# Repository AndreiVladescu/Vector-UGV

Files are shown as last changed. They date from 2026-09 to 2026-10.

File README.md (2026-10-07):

V.E.C.T.O.R.

# V.E.C.T.O.R.

An 18-DOF hexapod research platform: a smart controller per leg on CAN, a Raspberry Pi CM5 carrier, camera and SDR payload, ELRS / Wi-Fi / 4G links. Built for the [PCBWay 9th Project Design Contest](https://www.pcbway.com/activity/9th-project-design-contest.html).

- `docs/`: spec, connector pinouts, power budget, servo names and calibration
- `hardware/`: one KiCad project per board, shared library in `lib/`
- `mechanical/`: Fusion 360 exports (STEP, STL), harness drawings
- `firmware/`: STM32C092 code for the leg and power nodes, CAN bootloader
- `software/`: CM5 / Pi 5 side: ROS 2 workspace, tools, Docker
- `protocol/vector.dbc`: CAN message definitions, used by firmware and host
- `test-tools/`: bench sketches, e.g. `servo_test` (Arduino Uno, set a servo angle over serial and read the pot)

Start with `docs/spec.md`.

## Try it without hardware

Everything below runs on a PC with Ubuntu 24.04 or Linux Mint 22 and ROS 2 Jazzy (install commands in [`software/README.md`](software/README.md#desktop-setup-mint-223--ubuntu-2404)). The leg nodes run their real firmware logic against simulated servos on a virtual CAN bus.

```sh
cd software/ros2_ws
source /opt/ros/jazzy/setup.zsh                 # or setup.bash
colcon build --symlink-install && source install/setup.zsh

# virtual CAN bus (again after every reboot)
sudo modprobe vcan
sudo ip link add dev vcan0 type vcan && sudo ip link set up vcan0

ros2 run vector_hw sim_legs vcan0 --calibrated --limits -45.8,45.8,-80.2,80.2,-149,17  # terminal 1: six legs
ros2 launch vector_bringup robot.launch.py hardware:=can can_interface:=vcan0   # terminal 2: robot + rviz
ros2 run teleop_twist_keyboard teleop_twist_keyboard                           # terminal 3: drive (i, j, l, J, L, t, b, k)
candump vcan0 | cantools decode ../../protocol/vector.dbc                      # optional: watch the bus
```

Each new terminal needs the two `source` lines. Stop `sim_legs` while the robot runs and the hardware drops out after 100 ms, the same as it would with a dead leg. Without `--calibrated` the legs start like fresh boards; `leg_config.py` calibrates them (see `software/README.md`).

Without CAN: `robot.launch.py` alone (mock joints), or `sim_gazebo.launch.py world:=rough level:=true` for physics.

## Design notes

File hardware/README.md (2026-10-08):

# Hardware

One KiCad project per board: `side-board/`, `power-board/`, `carrier-cm5/`. The lib tables in each point to the shared library in `lib/`, so custom symbols and footprints go there.

- Connector pinouts come from `docs/interfaces.md`. Use the same footprint and pin order on both ends of a cable.
- Side board: draw the leg cell as one hierarchical sheet, use it three times, and copy the layout with KiCad's multichannel tools.
- Tag each fabbed revision (`side-board-revA`) and put the revision and git hash on the silkscreen. Gerbers, BOM and pick-and-place go in `<board>/production/<rev>/`.
- Hand assembly: 0402 minimum, one side where possible, test points and 0 Ω links on every rail.

`BOM_LCSC.csv` is a second way to buy the main parts for one robot: LCSC part numbers, quantities, prices and stock checked on 2026-10-08, and where each part is cheaper (LCSC, Mouser or TME). It loads straight into LCSC's BOM tool. Passives aren't in it yet.

## Power rails

Currents and loads are in `docs/power-budget.md`. No 5 V on the side boards: the CAN transceivers are 3.3 V parts (TI TCAN332DR).

```
PACK 4S3P 18650 (12.0–16.8 V)
│
└─ POWER BOARD ── BQ76952 high-side FETs ── VBAT
   │                                  (charging: BQ25798, fed by GX-12 12–24 V or USB-C PD 20 V)
   │
   ├─ LM5069 (hot-swap + e-stop) ── VBAT_L ──► SIDE BOARD L
   │                                  ├─ TPS56A37 ── 6V0_LEG1 ── 3× MG996R (+ pots)
   │                                  ├─ TPS56A37 ── 6V0_LEG2 ── 3× MG996R (+ pots)
   │                                  ├─ TPS56A37 ── 6V0_LEG3 ── 3× MG996R (+ pots)
   │                                  └─ low-Iq buck ── 3V3_LEG ── 3× STM32C092, 3× CAN xcvr,
   │                                                              3× VL53L1X, 3× INA181
   │
   ├─ LM5069 (hot-swap + e-stop) ── VBAT_R ──► SIDE BOARD R   (same as L)
   │
   ├─ 5 V / 6 A buck ── 5V_SYS ──► CARRIER
   │                                  ├─ CM5 ── 3V3 / 1V8 (CM5's own outputs)
   │                                  ├─ 2× USB-A (current-limit switches)
   │                                  ├─ SDR (AD9363), fan
   │                                  └─ 3V3_M2 ── Hailo M.2 (optional)
   │
   ├─ VBAT_SYS ──► CARRIER
   │                ├─ 3.8 V buck ── 3V8_LTE ── EC25-EUX
   │                └─ small 5 V buck ── gimbal (2× SG90)
   │
   └─ 3V3_PWR (TBD) ── STM32C092 on the power board, BQ76952 comms
```

3.3 V is made locally on each side board, not sent over the CAN harness: the STM32C0 ADC uses VDD as its reference, so a remote 3.3 V would put servo current noise on the pot and current readings, and a short on one side would take down the other.

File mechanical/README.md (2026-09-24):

# Mechanical

The live design lives in Fusion 360. This folder holds exports taken at milestones:
- `cad/fusion/`: `.f3z` archives
- `cad/step/`: assembly and parts
- `cad/pcb/`: board outlines (DXF, Fusion to KiCad) and board STEPs (KiCad to Fusion)
- `stl/`: named `<part>_<material>_x<qty>.stl`
- `harness/`: cable drawings

Board outline loop: sketch the outline and holes on the body in Fusion, export DXF, import to KiCad Edge.Cuts. After layout, export STEP back and check fit through the full leg range.

The free Fusion licence allows 10 editable documents, so keep most parts as internal components of one assembly. Keep leg lengths as user parameters, since the same numbers go in the URDF.

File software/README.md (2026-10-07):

# Software

Runs on the Pi 5 during development and on the CM5 later: Raspberry Pi OS, with ROS 2 Jazzy in Docker.

Packages in `ros2_ws/src/`:
- `vector_description`: URDF and `config/legs.yaml`, the one place leg lengths and hip positions live; `vector_cad.urdf.xacro` is the full Fusion 360 model, generated from the raw export `vector_cad_raw.urdf.xacro` by `tools/cad_urdf.py` (run it after every export; view the result with `ros2 launch vector_bringup view_cad.launch.py`)
- `vector_gait`: kinematics and gait in plain C++ (`vector_core`, no ROS), plus `gait_node`
- `vector_hw`: ros2_control hardware for the leg nodes over SocketCAN, plus `sim_legs` (the leg firmware logic with simulated servos) and `leg_config.py` (calibration and settings over CAN)
- `vector_bringup`: launch files, controller config, rviz config, Gazebo worlds
- `vector_link`: ExpressLRS (`elrs.py`), the cmd_vel mux and link watchdog, the operator page
- `vector_nav`: waypoint follower and obstacle grid
- `vector_tof`: the nose board's VL53L8CX
- `vector_io`: the carrier's IO MCU over UART2 (lidar, GNSS, ELRS frames, LoRa, housekeeping) and its flasher
- `vector_imu`: LSM6DSV16X on the carrier and MMC5983MA on the nose board -> `imu`, `mag`
- later: `vector_perception`

## Desktop setup (Mint 22.3 / Ubuntu 24.04)

```sh
sudo apt install curl
export ROS_APT_SOURCE_VERSION=$(curl -s https://api.github.com/repos/ros-infrastructure/ros-apt-source/releases/latest | grep -F tag_name | awk -F'"' '{print $4}')
curl -L -o /tmp/ros2-apt-source.deb "https://github.com/ros-infrastructure/ros-apt-source/releases/download/${ROS_APT_SOURCE_VERSION}/ros2-apt-source_${ROS_APT_SOURCE_VERSION}.$(. /etc/os-release && echo $UBUNTU_CODENAME)_all.deb"
sudo dpkg -i /tmp/ros2-apt-source.deb
sudo apt update
sudo apt install ros-jazzy-desktop ros-jazzy-ros2-control ros-jazzy-ros2-controllers \
  ros-jazzy-xacro ros-jazzy-teleop-twist-keyboard ros-jazzy-plotjuggler-ros \
  ros-jazzy-ros-gz ros-jazzy-gz-ros2-control ros-jazzy-robot-localization \
  ros-jazzy-nmea-navsat-driver ros-jazzy-joint-state-publisher-gui \
  python3-colcon-common-extensions python3-can can-utils
pip install --user --break-system-packages cantools
```

On Mint the `UBUNTU_CODENAME` line resolves to `noble`, which is what the ROS repo needs.

## Kinematic sim

```sh
cd software/ros2_ws
source /opt/ros/jazzy/setup.zsh          # setup.bash in bash
colcon build --symlink-install && source install/setup.zsh

ros2 launch vector_bringup robot.launch.py               # mock joints
ros2 run teleop_twist_keyboard teleop_twist_keyboard     # second terminal
ros2 param set /gait_node gait ripple                     # tripod / ripple / wave, while standing
ros2 param set /gait_node body_pitch 0.15                 # body_x/y/z/roll/pitch/yaw, live
```

Teleop keys (the teleop terminal needs focus). By default a key latches: the robot keeps doing it until the next key, and `k` stops. For hold-to-move instead, `ros2 param set /gait_node cmd_timeout 0.6`: it walks while the key is held (keyboard auto-repeat) and stops 0.6 s after release.

| Key | Motion |
|---|---|
| `i` `,` | forward / back |
| `j` `l` | turn left / right |
| `u` `o` `m` `.` | forward or back while turning |
| `J` `L` (shift) | strafe left / right |
| `U` `O` `M` `>` (shift) | diagonal |
| `t` `b` | body 5 mm up / down per press, −40 to +30 mm; doesn't stop the walk |
| `k` | stop |
| `q`/`z`, `w`/`x`, `e`/`c` | all / linear / turn speed ±10% |

Teleop starts at 0.5 m/s but the gait caps walking at about 0.12 m/s (6 cm stride), so the speed keys only show once you're below that. Speed changes ramp at 0.25 m/s² (`accel`, `turn_accel`), so starting, stopping and switching direction take about half a second. Switching gait needs the robot standing: press `k` first. In rviz the camera follows the robot, so strafing shows as the grid and foot trails sliding sideways.

Mock hardware, so the joints go exactly where they're told. Useful for checking foot paths (the coloured trails), reach and joint speeds (PlotJuggler on `/joint_states`), not loads. Change geometry in `legs.yaml` and relaunch.

## Gazebo

```sh
ros2 launch vector_bringup sim_gazebo.launch.py                      # flat ground
ros2 launch vector_bringup sim_gazebo.launch.py world:=slope level:=true
ros2 launch vector_bringup sim_gazebo.launch.py world:=rough rviz:=true
```

Same controllers and gait node, with masses from `legs.yaml` and the joint effort capped at MG996R stall (1.08 N·m). Joint torques are in the `effort` field of `/joint_states`, ground truth pose on `/ground_truth`, IMU on `/imu`. Gazebo's position control is an idealised servo, so trust standing torques more than walking peaks.

Worlds: `flat`, `slope` (8°), `rough` (40 slabs, 1–3 cm, fixed layout). `level:=true` (or `ros2 param set /gait_node level true`) feeds the IMU tilt back into the body pose. On the 8° slope the body goes from −8.0° to 0.0°.

The lidar and the leg ToF sensors are simulated too: a 360-ray GPU lidar on `/scan` (5 Hz, 0.15–6 m, like the LDS01RR, at the `lidar` frame on the top plate) and one ray per `<leg>_tof` (1.3 m), which `sim_tof.py` turns into the same `legs/<leg>/tof` Range messages `leg_monitor` publishes. So `nav:=true` runs the obstacle map on them. They render, so a headless Gazebo starts with `--headless-rendering`. Standing on flat ground every leg ray meets the ground about 0.4 m out; a wall put 1 m ahead reads 0.94 m on the lidar and 0.92 m in the map (`test_gazebo_sensors.py`).

## Sentinel Stance

```sh
ros2 service call /gait_node/sentinel std_srvs/srv/Trigger   # stop, lower onto the belly, legs off
ros2 service call /gait_node/wake std_srvs/srv/Trigger        # legs on, wait for all six, stand up
ros2 topic echo /gait_node/mode                                # walk, stopping, lowering, sentinel, powering, raising, halted
ros2 service call /gait_node/estop std_srvs/srv/SetBool "{data: true}"   # e-stop; false releases, then wake
```

The legs switch through the `leg_power` GPIO controller (`legs/enable`): on CAN it sets the enable bit in `LEG_CMD`, and its state reads 1 only when all six legs report active. If they don't within `power_timeout` (10 s) the robot stays down. Keys are ignored while sitting or getting up. Sitting down, the feet first step out to `sentinel_reach` (140 mm) in wave order, so five legs carry the body while one moves, then the hip goes down to `sentinel_height` (30 mm), just above where the belly touches; getting up does the same in reverse. At the standing reach the tibia limit would stop the hip at about 41 mm. `gait_report` checks the whole sequence (the `sentinel` row). In Gazebo there is no leg power, so it only does the moves.

If a leg drops out while walking (a fault, see below), the node stops in `halted`: the other legs finish their step and stand, keys are ignored. Sentinel then wake power-cycles the legs, which clears the fault if its cause is gone.

E-stop sets the flag in SYNC (`legs/estop`): every leg switches off at once, which drops the body, and the node goes straight to sentinel. Wake is refused until the e-stop is released. The hardware e-stop line to the legs does the same without ROS.

## Touchdown (off by default)

`touchdown:=true` makes each foot stop where it meets the ground late in its swing, or probe up to 20 mm deeper into a hole; stance feet then keep their own height. Contact comes from `contact_from: position` (measured foot higher than anything commanded in the last 40 ms, from the pots) or `load` (femur + tibia torque, leg current on the robot).

In Gazebo it isn't convincing yet: on the rough world tilt goes from 2.7° to 2.0–2.5° RMS, but on flat ground the body bobs 2–5 mm more, and the gain with `load` came from feet pressing down, not from contact being sensed. Gazebo's servo is ideal and stiff; tune this against the real MG996R (pot error and leg current when a foot is blocked) before turning it on.

## CAN without hardware

`sim_legs` runs the actual leg firmware logic (`firmware/leg-node`) six times, each with three simulated MG996Rs that behave like the bench measurements (wiper noise, speed, the restart quirk), on a virtual CAN bus. `vector_hw` builds it.

```sh
sudo modprobe vcan && sudo ip link add dev vcan0 type vcan && sudo ip link set up vcan0   # again after a reboot
ros2 run vector_hw sim_legs vcan0 --calibrated --limits -45.8,45.8,-80.2,80.2,-149,17   # joint limits from legs.yaml
ros2 launch vector_bringup robot.launch.py hardware:=can can_interface:=vcan0
candump vcan0 | cantools decode ../../protocol/vector.dbc      # watch the traffic
```

Without `--calibrated` the legs start like fresh boards and refuse to wake until calibrated. Try the calibration mode on them:

```sh
ros2 run vector_hw leg_config.py --channel vcan0 status
ros2 run vector_hw leg_config.py --channel vcan0 calibrate R1 --mode limits
ros2 run vector_hw leg_config.py --channel vcan0 push     # docs/servos.md + legs.yaml, run from the repo
```

On the real robot it's the same launch with `can_interface:=can0` (CANable on the Pi 5, MCP251863 on the carrier). The hardware waits for all six legs before activating, starts from their measured angles, and drops out if a leg is silent for 100 ms; SYNC then stops, and every leg crouches and powers down on its own. Walking at 200 Hz uses about 32% of the 1 Mbit/s bus.

With `hardware:=can` the launch also starts `leg_monitor`, which listens on the same bus:

```sh
ros2 topic echo /diagnostics          # per leg: state, faults, current, battery, servo rail, temperature, ToF
ros2 run rqt_robot_monitor rqt_robot_monitor
ros2 topic echo /legs/L1/tof          # sensor_msgs/Range in frame L1_tof (+inf: nothing in range)
```

Fault changes also go to the log as they happen. The `<leg>_tof` frames sit on the tibia links where the CAD has the sensor (`tof` in `legs.yaml`), with x along the beam.

## Power board

`sim_power` runs the power board firmware (`firmware/power-node`) against models of the BQ76942 and BQ25798 and a 4S pack that drains with what is switched on. `power_monitor` (started with `hardware:=can`) turns its frames into ROS:

```sh
ros2 run vector_hw sim_power vcan0 --soc 40          # ends when the board switches itself off
ros2 topic echo /battery                             # BatteryState at 10 Hz, current negative while discharging
ros2 service call /power/shutdown std_srvs/srv/Trigger              # the board asks the CM5 to halt
ros2 run vector_hw leg_config.py --channel vcan0 power              # state, cells, charger, settings
ros2 run vector_hw leg_config.py --channel vcan0 power set charge_ma 2500 --save
ros2 run vector_hw leg_config.py --channel vcan0 power set cell_ntc 1 --save   # DIY pack with a thermistor; next power-up
```

`power_monitor` also puts battery, board and charger entries in `/diagnostics` and a latched `power/estop`. When the board starts a shutdown, or the charge falls under `sentinel_soc` (10 %) while discharging, it calls `gait_node/sentinel` so the robot sits down before the power goes. `kill -USR1` / `-USR2` on `sim_power` press the power button and plug / unplug USB-C.

## Radio and links

With `links:=true` (`LINKS=true` in `/etc/vector.env`, the default with `can0`) `link_manager.py` is the only node that writes `cmd_vel`, from the first of: the ExpressLRS radio while armed (`cmd_vel/elrs`), an operator over Wi-Fi or LTE (`cmd_vel/teleop`), the GPS mission (`cmd_vel/nav`). The operator counts as connected while teleop commands or `operator/heartbeat` (std_msgs/Empty, about 1 Hz, e.g. from a Foxglove publish panel) keep coming. With no radio and no operator for 5 s the robot walks back to its home point if it has one and a GNSS fix (`return_home`, on by default; needs `nav:=true`), and sits down there; without them it sits down where it is. Either way it stays down until woken, and a link coming back on the way home cancels the walk and hands control back. Home is the first GNSS fix after start, or wherever Set home on the page puts it (`home/set`, latched on `home`). Otherwise a mission only moves while a link is up (`missions_alone` to change that).

```sh
ros2 run teleop_twist_keyboard teleop_twist_keyboard --ros-args -r cmd_vel:=cmd_vel/teleop
ros2 topic pub -r 1 /operator/heartbeat std_msgs/msg/Empty
ros2 topic echo /links/active          # elrs, teleop, nav or idle
```

The operator page, `http://<robot>:8080` on a phone or laptop (started with `links:=true`): the YOLO video, battery, links and gait mode, a joystick (forward and turn, or sideways), Sit / Wake / E-STOP, a map with the GNSS position where tapping adds waypoints to send as a mission, and a systems panel (antenna button) with the carrier's battery, 5 V rail and board temperature, the GNSS, lidar, receiver, IMU and compass state, the LoRa beacon count and the last packet received, the LTE supply switch and a Beep button to find the robot. The map button shows a mini map in the bottom-left corner (the joystick moves to its right), north up, centred on the robot with its track and route; tapping it opens the big map; the tiles button picks which small readouts stay on screen (ELRS link quality and RSSI, Wi-Fi, LTE, LoRa RSSI and SNR, position, GNSS, altitude, heading, tilt, speed, battery, carrier rail, nearest obstacle, distance home, mission, latency). Both choices are kept in the browser. The battery shows the time left at the last minute's average draw, from the power board's capacity and charge (a warning at 10 minutes).

The systems panel also has Save black box and Calibrate legs. `blackbox.py` (always running) keeps the last two minutes of the joints, commands, gait mode, diagnostics, battery, IMU, GNSS, links, mission and obstacles in memory and writes them 10 s after an e-stop, a leg fault, a new leg, power or link error, a fall (tilt over 45°) or the button, as an MCAP bag in `~/.ros/blackbox` (`/var/lib/vector/blackbox` on the host in Docker; the newest 30 kept). Open it in Foxglove or play it back with `ros2 bag play`. The calibration wizard runs `leg_config.py`'s sweep on one leg over CAN (`can_interface`) with the legs off: sit the robot down, support the body so the leg hangs free, pick the leg, the joints and the range, Start; then Save to the leg, or copy the rows for `docs/servos.md`. While it's open it sends the operator heartbeat; commands stop 0.4 s after the last one, so a phone that drops out doesn't leave the robot walking. The map tiles come from OpenStreetMap, so they need internet on the phone; the rest doesn't. Anyone who can reach port 8080 can drive the robot: keep it on Tailscale, or set `page_key:=...` and open `http://<robot>:8080/?key=...`.

`elrs.py` reads an ExpressLRS receiver in CRSF mode (420000 baud) on UART2 (GPIO4 TX, GPIO5 RX, `/dev/ttyAMA2`) on the Pi; on the carrier the receiver hangs off the IO MCU and `elrs_port:=io` takes its frames from `io_bridge`. Mode 2: right stick forward / sideways, left stick sideways turns and up / down sets the top speed (30-100 % of 0.1 m/s). AUX1 arms, AUX2 high sits down (low wakes), AUX3 high is the e-stop. The handset shows the battery (voltage, current, used mAh, %) and the gait mode as telemetry. Set the receiver to failsafe "no pulses", so a lost link stops the sticks.

The LTE modem (A7670E) in RNDIS / ECM mode is a wired interface to Linux; `setup.sh` adds a NetworkManager profile that matches it by driver and puts it behind Wi-Fi (route metric 700). `/diagnostics` shows the control source, the Wi-Fi signal and the modem's state, plus its signal with `LTE_AT=/dev/ttyUSB2` (the AT port number can differ; `AT+CSQ` is plain 3GPP). The APN and the modem's USB mode are set once with its own AT commands, see SIMCom's A76XX documents.

## GNSS and waypoints

Position is GNSS first: `robot_localization` runs two EKFs (leg odometry `odom/legs` from `gait_node` plus the IMU for `odom -> base_link`; the same plus GNSS through `navsat_transform` for `map -> odom`), and `waypoints.py` walks GPS points. Config in `vector_nav/config/localization.yaml`.

```sh
ros2 launch vector_bringup robot.launch.py hardware:=can gnss_port:=/dev/ttyAMA0 nav:=true
ros2 launch vector_bringup sim_gazebo.launch.py nav:=true                 # simulated GNSS, 0.5 m noise
ros2 run vector_nav waypoints.py send 44.42690,26.10280 44.42700,26.10260
ros2 topic echo /mission/status
ros2 run vector_nav waypoints.py cancel
```

The receiver is any NMEA module on UART0 (GPIO14 TX, GPIO15 RX, 3.3 V), 115200 baud (`gnss_baud`); `setup.sh` enables the UART and passes `/dev/ttyAMA0` into the container (`GNSS=` and `NAV=` in `/etc/vector.env`). A mission is refused until there is a fix, and the robot stops while the fix or the filtered position is stale. It only sends `cmd_vel` while a mission runs, so teleop still works otherwise; the Gazebo world's origin is 44.4268 N, 26.1025 E.

`obstacles.py` (also started by `nav.launch.py`) keeps what sticks out of the ground for 3 s in `odom`: where YOLO's objects meet the ground (the lowest mask pixel per column, projected from the camera pose on flat ground), the nose ToF zones and the six leg ToF rays more than 5 cm above the ground. It publishes `obstacles/grid` (OccupancyGrid, for Foxglove) and `obstacles/clearance` (free metres straight ahead, and the side with more room). The follower stops with less than 0.6 m free, and after 2 s steps sideways around it; without obstacle data it walks on GNSS alone.

`navsat_transform` needs an absolute heading from the IMU (0 = east). Gazebo's IMU has one; on the robot it comes from `imu_node.py` with the nose board's compass (below). Without the nose board the IMU's yaw is gyro only and `nav:=true` has no heading.

## Operator page demo

Everything the page shows, on the desktop with no hardware: the mock robot and gait, the link manager and the page, the carrier's IO MCU simulated on a pseudo-terminal (`sim_io.py`, speaking the real link protocol to the real `io_bridge`) and `imu_node` on simulated chips. Walking from the page moves the GNSS position (`gnss_scale` multiplies it, so the map shows it), the heading, the lidar's view of a 6 x 4 m yard and the battery current; ELRS link quality wanders, a LoRa "ping" arrives every 20 s, Beep and the LTE switch reach the simulated MCU. The nav stack runs too, so missions and Go home work, and switching the radio off (below) with the page closed walks the robot home. The calibration wizard talks to `sim_legs` on `vcan0` when that runs (the `sim` profile in Docker).

```sh
ros2 launch vector_bringup demo.launch.py gnss_scale:=20       # then http://localhost:8080
ros2 param set /sim_io radio false                              # also lidar, gnss, lora
ros2 param set /sim_io vbat 13.3                                # low battery
```

On the desktop there's no video; the page shows NO VIDEO until a stream answers.

The robot view draws the CAD model seen from above (`vector_description/config/silhouette.json`, written by `tools/cad_urdf.py` with the URDF, about 14 kB gzipped), moved by the real joint angles; without that file it falls back to lines. The 3D button on that card shows the CAD model in 3D instead (`robot3d.json`, the meshes simplified on a 2 mm grid: 87k triangles, about 460 kB gzipped, loaded with three.js only when opened); drag to look around, `?view=3d` opens the page in it. Without WebGL or the file it stays 2D.

On the Pi (or the robot) in Docker: `DEMO=true` in `/etc/vector.env` (or `sudo DEMO=true software/host/setup.sh`) makes the robot container start the demo instead, `DEMO_GNSS_SCALE` sets the scale (default 20). `sudo systemctl restart vector-stack`, then `http://<pi>:8080`; with the vision profile the page also shows the camera with YOLO. `DEMO=false` and another restart go back to the robot.

## Carrier IO MCU and IMU

The STM32C092 next to the CM5 (`firmware/io-node`) carries the ELRS receiver, the LDS01RR lidar, the MAX-M10S, the RFM95W and the battery / 5 V / NTC sensing, and talks to the CM5 on UART2 at 1 Mbaud. `io_bridge.py` turns that into `scan` (LaserScan, frame `lidar`), `gnss/nmea_sentence` (and through `nmea_topic_driver` the usual `gnss/fix`, `gnss/vel`), `io/crsf` for `elrs.py`, `lora/rx` / `lora/tx` and an `io: mcu` entry in `/diagnostics`. The MCU sends a LoRa position beacon every 30 s on its own (`beacon_s`, 0 = off), so a lost robot can be found with any SX127x receiver.

```sh
ros2 launch vector_bringup robot.launch.py hardware:=can io_port:=/dev/ttyAMA2 elrs_port:=io imu:=true nav:=true
ros2 service call /io/lte_power std_srvs/srv/SetBool "{data: true}"
ros2 param set /io_bridge lidar_rpm 0                      # lidar motor off (300 = 5 scans/s)
ros2 run vector_io io_flash.py io-node.bin                 # new IO firmware through the ROM bootloader
```

`imu_node.py` reads the LSM6DSV16X (0x6A) and the MMC5983MA (0x30) on I2C1 and publishes `imu` with the orientation in ENU, fused from gyro, accelerometer and compass, and `mag`. Keep the robot still for the first 2 s (gyro bias). `imu_axes` / `mag_axes` map each chip onto `base_link` and `declination_deg` (6 for Bucharest) turns magnetic north into true north. Calibrate the compass once it sits in the robot: `ros2 service call /imu/calibrate_mag std_srvs/srv/Trigger`, then turn the robot through every orientation for 30 s and copy the logged `mag_offset` / `mag_scale` into the launch parameters. In the container: `IO_PORT=/dev/ttyAMA2`, `ELRS_PORT=io` and `IMU=true` in `/etc/vector.env`.

## On the robot (Docker)

The robot runs the same packages in one image (no Gazebo or rviz), built natively on the Pi / CM5 in about 2.5 minutes:

```sh
docker build -f software/docker/Dockerfile -t vector .                        # from the repo root
docker build -f software/docker/Dockerfile --target build -t vector:build .   # with the tests
CAN_INTERFACE=can0 docker compose -f software/docker/compose.yaml up -d      # robot + foxglove_bridge
CAN_INTERFACE=vcan0 docker compose -f software/docker/compose.yaml --profile sim up -d   # with sim_legs
```

`.dockerignore` keeps the CAD meshes and the raw Fusion export out of the image: the robot has no rviz, and the operator page only needs `silhouette.json`. To update a Pi without git, copy the tree over from the desktop and build there:

```sh
rsync -a --exclude build/ --exclude install/ --exclude log/ --exclude meshes/ -R software firmware protocol docs .dockerignore pi@<pi>:vector/
```

Always run ROS containers with a normal open-files limit (`nofile: 65536`, set in `compose.yaml`). Docker's default is about 2^30, and LTTng, which every ROS 2 process loads through `tracetools`, allocates a bitmap sized by it: 128 MB per process, 1.4 GB for this stack.

Measured on a Pi 5 2 GB (`software/tools/`): the stack uses 481 MB system-wide, Docker itself 133 MB of that; SYNC runs at 5.00 ms with a worst gap of 8 ms idle and 15 ms with all four cores busy (the legs crouch after 100 ms); the control loop gets SCHED_FIFO 50.

To make a fresh Pi OS install start everything on its own, run once from the repo root:

```sh
sudo software/host/setup.sh                                  # real legs on can0, vision on
sudo CAN=vcan0 PROFILES=sim,vision software/host/setup.sh    # bench, with sim_legs
```

It installs Docker (default nofile 65536, logs to journald) and adds `vector-can` (can0 at 1 Mbit/s or vcan0), `vector-camera` (rpicam-vid) and `vector-stack` (`docker compose up -d`), and arms the hardware watchdog at 15 s. Settings live in `/etc/vector.env`. From power-on on the Pi 5 (NVMe): Linux ready in 10.7 s, legs active at 13.3 s, first YOLO result at about 18 s.

### A card for the robot (CM5 on microSD)

```sh
software/image/make_card.sh vector.img --ssid Home --ssh-key ~/.ssh/pi5.pub      # an image file, flash it later
sudo software/image/make_card.sh /dev/sdX --ssid Home --ssh-key ~/.ssh/pi5.pub   # straight to a card
```

It takes the latest Raspberry Pi OS Lite (arm64, checked against its SHA-256), and puts in the boot partition a cloud-init `user-data` (hostname `vector`, user `pi` with only the SSH key, Wi-Fi or Ethernet) and this checkout's code as `vector.tar.gz` (the GitHub repo is private, so nothing is cloned; `VERSION` in it says which commit, and whether there were local changes). On first boot `firstboot.sh` runs `setup.sh`, builds the three images, exports the YOLO model and reboots into the running stack: about 20 minutes with internet, log in `/var/log/vector-firstboot.log`. `--can vcan0 --profiles sim,vision` makes a test box.

`setup.sh` also looks after the card: the journal stays in RAM (64 MB), swap only in zram, `fsck.repair=yes`. The root filesystem stays writable, since Docker's storage can't sit on an overlay root without a partition of its own; a clean halt through the power board is what keeps it intact.

## Camera and YOLO

The camera stays on the host, where libcamera is native, and hands raw frames to the vision container over a local socket; nothing is encoded twice. YOLO runs from ONNX with ONNX Runtime (`software/vision/yolo_onnx.py`), no PyTorch on the robot; PyTorch and Ultralytics live only in an export image, used once:

```sh
docker build -f software/vision/Dockerfile --target export -t vector-yolo-export .
SIZES="320 480" docker run --rm -e SIZES -v docker_models:/models vector-yolo-export    # yolo26n(-seg)-<size>.onnx
docker build -f software/vision/Dockerfile -t vector-vision .
docker compose -f software/docker/compose.yaml --profile vision up -d                    # YOLO + MediaMTX
YOLO_MODEL=yolo26n-480.onnx docker compose -f software/docker/compose.yaml --profile vision up -d
```

`yolo_node.py` publishes `/yolo/detections` (vision_msgs), `/yolo/mask` (class id + 1 per pixel) and `/yolo/debug/compressed`, and streams the annotated video through MediaMTX:

- VLC: `rtsp://<robot>:8554/yolo`
- Firefox / any browser: `http://<robot>:8889/yolo` (WebRTC)

On the Pi 5 2 GB, CPU only, with the control stack running alongside (SYNC never gaps more than 8 ms):

| Model | fps | frame to result | node memory |
|---|---|---|---|
| yolo26n-seg, 320 px | 12.2 | 112 ms | 147 MB |
| yolo26n-seg, 480 px | 5.2 | 225 ms | 182 MB |
| yolo26n, 320 px | 14.4 (camera-limited) | 86 ms | 136 MB |
| yolo26n, 480 px | 7.2 | 167 ms | 162 MB |

The camera captures at 1280x960 (`CAMERA_WIDTH`/`CAMERA_HEIGHT` in `/etc/vector.env`); the model gets a 320 px copy and the masks and boxes are scaled back and drawn on the full frame, so the stream stays sharp. That costs about 1 fps over a 640x480 capture (9 vs 10 fps with the stream on), and the 1280x960 encode takes 16 % of one core.

With the nose board fitted, `tof_front` (`vector_tof`, started with `hardware:=can`) runs the VL53L8CX through ST's ULD on `/dev/i2c-1`: `nose/tof/points` (a point per zone) and `nose/tof/depth` (8x8 metres, NaN = nothing). `yolo_node` takes the zones behind each box, uses a low percentile so the object wins over the background, prints the distance on the stream and publishes `~/detections_3d`. The ULD sources, with the sensor's firmware, are downloaded at build time from ST's X-CUBE-TOF1 (BSD-3-Clause), pinned by hash. The zone grid's orientation (`flip_x`, `flip_y`) needs a check on the bench: a hand in the top left corner should show in row 0, column 0 of the depth image.

Ultralytics itself runs the same ONNX model at half the speed and needs 430 MB, most of it PyTorch. The YOLO26 weights are AGPL-3.0 (Ultralytics), fine for an open project.

## Checks

```sh
ros2 run vector_gait gait_report src/vector_description/config/legs.yaml --mass 3.0
colcon test --ctest-args -LE gazebo          # unit tests, kinematic sim, CAN loop (skips without vcan0)
                                             # also checks that the DBC, firmware, C++ and leg_config.py agree
colcon test --ctest-args -L gazebo           # headless Gazebo: flat walk, slope leveling, rough walk
colcon test-result --verbose
```

`gait_report` runs every gait offline and flags joint speeds over the servo limit, joints near their limits, low stability margin and static torques over half of stall. Rerun it whenever `legs.yaml` changes.

With the CAD legs (coxa 51 / femur 67.6 / tibia 118.6 mm), 3 kg and the stance in `legs.yaml` (reach 108 mm, hip 100 mm): standing takes 2.9 kg·cm on the femur; the static worst case is 7.4 kg·cm walking forward and 8.3 sideways (tripod), so the femur servos work at up to about 75% of stall. Every joint keeps at least 10° from its limits in every gait, the stability margin is at least 73 mm, and walking stays in range from about 95 to 130 mm hip height (hence `height_min` -0.005 in `gait.yaml`). Femur torque follows the reach: each 4 mm less saves about 0.4 kg·cm but costs tibia margin. Wave runs at a 2 s period (`wave_period`) to stay under the servo speed; tripod and ripple keep 1 s. Sitting down (Sentinel) peaks at 7.8 kg·cm while the feet step out.

`tools/` holds bring-up scripts (python-can, cantools), the CAN flasher and the robot-side tests: `sync_jitter.py` (SYNC timing), `mem_report.py` (memory per process), `walk_test.py` (walk, turn, Sentinel and wake in a loop while watching the legs, run inside the robot container) and `soak.py` (a line a minute of memory, temperature, CPU, SYNC and YOLO rate).

## When the robot doesn't move

1. Leftovers from earlier runs. A closed terminal or a crashed launch can leave a Gazebo server or an old `gait_node` running; the next launch then talks to the old controller manager and the new robot gets no controllers. `sim_gazebo.launch.py` prints a warning if it finds an old Gazebo. Clean up with:
   ```sh
   pkill -f "gz sim"; pkill -f gait_node; pkill -f ros2_control_node; ros2 daemon stop
   ```
2. Controllers: `ros2 control list_controllers` should show `joint_state_broadcaster` and `leg_controller` as active.
3. Commands arrive: `ros2 topic echo /cmd_vel` while pressing keys, and `ros2 node list` should show one `/gait_node`. The teleop terminal needs keyboard focus.
4. After pulling changes to C++ code, rebuild (`colcon build --symlink-install`) and re-source `install/setup.zsh` in every terminal.

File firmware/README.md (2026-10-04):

# Firmware

STM32C092 for all nodes, bare-metal on ST's HAL, built with CMake and arm-none-eabi-gcc. Each node keeps its logic in plain C under `src/`, tested on the PC against simulated hardware, and a thin `stm32/` layer for the chip.

- `common/`: CAN frames (`vector_can`, matching `protocol/vector.dbc`) and the bootloader protocol (`boot`)
- `stm32c0/`: shared by every node: clocks and FDCAN (`mcu.c`, `MCU_NO_HSE` for a board without a crystal), the CAN bootloader, flash map and linker scripts, the build helper (`stm32c0.cmake`), `flash_swd.sh`
- `leg-node/`: servo PWM, pot and current ADC, ToF, wake, calibration, protection, self-test
- `power-node/`: BQ76942 setup, BQ25798 charger, state of charge, power states, soft power and the ROS e-stop
- `io-node/`: the carrier's IO co-processor: ELRS, LDS01RR lidar, GNSS, LoRa beacon, ADC, buzzer, LTE supply, one UART to the CM5 (no CAN, flashed through ST's ROM bootloader)

First flash over SWD with `stm32c0/flash_swd.sh`, then over CAN with `leg_config.py flash`. A node with a broken application can still be reached through the bootloader's 200 ms window after reset.

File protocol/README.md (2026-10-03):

# CAN protocol

`vector.dbc` defines every message on the leg bus. Classic CAN, 1 Mbit/s, 11-bit IDs.

`ID = (function << 4) | node`. Nodes: 1–3 = L1–L3, 4–6 = R1–R3, 7 = power board, 0 = CM5 / broadcast.

| Function | Message | Direction | Rate |
|---|---|---|---|
| 0 | SYNC (counter, mode, e-stop) | CM5 → all | 200 Hz |
| 1 | LEG_CMD (3 targets, enable) | CM5 → leg | 200 Hz |
| 2 | LEG_STATE (3 positions, current) | leg → CM5 | 200 Hz |
| 3 | LEG_STATUS (ToF, VBAT, 6 V rail, temp, faults, state) | leg → CM5 | 50 Hz |
| 4 | POWER_STATE (pack V/I, SoC, temp, state, flags, faults) | power → CM5 | 10 Hz |
| 5 | LEG_CONFIG (joint, key, value, seq, op) | CM5 → leg / power | on demand |
| 6 | LEG_REPLY (joint, key, value, seq, status) | leg / power → CM5 | on demand |
| 7 | BOOT (op, payload) | CM5 → leg / power | during an update |
| 8 | BOOT_REPLY (op, status, arg) | leg / power → CM5 | during an update |
| 9 | POWER_CELLS (4 cell voltages) | power → CM5 | 1 Hz |
| 10 | POWER_DETAIL (BMS safety status, FETs, USB-C and charger status) | power → CM5 | 1 Hz |

Units: 0.01°, mV, mA, mm. VBAT and the 6 V rail travel in 10 mV steps. ToF: 0 = no sensor or no fresh reading, 65535 = nothing in range.

Leg state: 0 off, 1 wake, 2 active, 3 crouch, 4 calibrate, 5 fault, 6 self-test. Fault bits: watchdog, e-stop, wake failed, uncalibrated, buck (power-good lost), overload (stall current or hot board), calibration failed, config.

Config ops: 0 read, 1 write, 2 save to flash, 3 calibrate (value 0 full, 1 limits; joint 255 = all three), 4 defaults, 5 self-test. Keys, per joint (0–2) or for the whole leg (joint 255), integer on the wire:

| Key | | Scale |
|---|---|---|
| 1 | wiper mid, mV at 1500 µs | ×10 |
| 2 | wiper slope, mV/µs | ×10⁴ |
| 3 | centre, µs at joint angle 0 | ×10 |
| 4 | direction | ±1 |
| 5 | µs per degree | ×1000 |
| 6, 7 | min / max angle, deg | ×100 |
| 8 | fit error, mV (read only) | ×10 |
| 9 | calibrated (read only) | 0/1 |
| 16 | leg: firmware version, short git hash, bit 28 = built with local changes (read only) | |
| 17 | leg: last reset, bits power, pin, watchdog, software, other (read only) | |
| 18 | leg: CAN bus-off count << 16, dropped tx frames (read only) | |
| 19 | leg: uptime, s (read only) | |
| 20, 21 | leg: VBAT / 6V0 divider correction, 0.8–1.2 | ×10⁴ |
| 22 | leg: current amp zero, mA, measured while off (read only) | |

Joint writes, save and defaults answer busy unless the leg is off or faulted (servos unpowered); the leg-wide corrections can be written any time. An e-stop (pin or SYNC flag) also ends a calibration or self-test, which then replies done, as failed.

Reply status: 0 ok, 1 bad key, 2 bad value, 3 busy, 4 calibration result (one per key: mid, slope, fit error), 5 calibration failed, 6 calibration done, 7 test pass, 8 test fail, 9 test done (value = failures).

Self-test (leg off; about 350 ms): buck off, then on for 200 ms with no pulses. One pass/fail reply per item, key = item, value = reading: 1 current zero (mA, < 100), 2 6V0 with the buck off (mV, < 500), 3 VBAT (mV, 9–26 V), 4 temperature (°C, 0–60), 5 power good, 6 6V0 with the buck on (mV, 5.7–6.3 V), 7 current with the buck on (mA, < 1500), 8 ToF (mm, not 0), 9–11 wipers (mV, 100–3200: a servo is plugged in). `leg_config.py` in `vector_hw` wraps all of this.

## Power board (node 7)

Power state: 0 boot (setting up the BMS), 1 charge (awake only to charge, CM5 off, servo bucks off), 2 on, 3 halting (asked the CM5 to shut down, waiting for its halted line, 30 s at most), 4 off (FETs open, BMS going to SHUTDOWN), 5 fault (BMS not answering at boot; retried every 5 s).

POWER_STATE: current is positive while charging. Flags: charger plugged in, charging, e-stop (ESTOP_N is low), low battery (SoC under 15 % or a cell within 100 mV of the shutdown voltage). Faults: BMS protection tripped, BMS not answering, charger fault, 5 V rail not good, cell under the shutdown voltage, cells more than 100 mV apart, config (flash empty, defaults in use), hot (a cell over 50 °C or the FETs over 80 °C).

POWER_DETAIL: BQ76942 Safety Status A/B/C as they come (A: SCD, OCD2, OCD1, OCC, COV, CUV in bits 7–2; B: OTF, OTINT, OTD, OTC, UTINT, UTD, UTC), FET Status bits 0–3 (CHG, PCHG, DSG, PDSG), bit 4 USB-C present, BQ25798 CHG_STAT and FAULT_Status_0, VBUS in 100 mV steps, FET temperature.

The power board sees SYNC too: while its e-stop flag is set (and SYNC keeps coming) it pulls ESTOP_N low, which holds every leg cell's servo buck off in hardware.

Config uses the leg frames with joint 255 and these keys (16–19 as for a leg):

| Key | | Range |
|---|---|---|
| 32 | pack capacity, mAh | 1000–30000 |
| 33 | charge current, mA | 100–5000 |
| 34 | charge voltage for the pack, mV | 12000–16800 |
| 35 | charger input current limit, mA | 100–3300 |
| 36 | cell voltage that shuts the robot down (10 s below it), mV | 3000–3700 |
| 37 | thermistor on J-NTC: 1 = fitted (TS1 is the cell temperature), 0 = none (the BMS die stands in); saved, applies at the next power-up | 0–1 |
| 38 | state of charge, 0.1 %; write to correct the gauge | 0–1000 |
| 39 | read only: BQ76942 data memory, value = address (0x9180–0x93FF), reply = 4 bytes from there | |
| 40 | write 1: shut down (same as a long press) | |

Ops: read, write, save (also stores the current SoC), defaults.

Bootloader ops (byte 0; the reply echoes it with bit 7 set, byte 1 is the status, bytes 2–5 a little-endian argument):

| Op | | Payload | Reply argument |
|---|---|---|---|
| 1 | ENTER | `boot` | version, bit 8 image valid, bits 16+ space in KB |
| 2 | INFO | – | as ENTER |
| 3 | ERASE | image size, u32 | bytes erased |
| 4 | DATA | seq, up to 6 bytes | next seq, bytes written << 8 |
| 5 | DONE | CRC32 (zlib) of the image padded to 8 bytes with 0xFF | bytes written |
| 6 | RUN | – | – |

Status: 0 ok, 1 bad op, 2 bad sequence, 3 flash error, 4 bad CRC, 5 too big, 6 no image, 7 busy (leg powered). A repeated DATA seq is acked again without writing, for when an ack got lost.

```sh
cantools generate_c_source vector.dbc -o ../firmware/common/
candump can0 | cantools decode vector.dbc
```

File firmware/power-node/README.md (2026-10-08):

# Power node

STM32C092 on the power board, CAN node 7. It sets up the BQ7694202 and the BQ25798 (their settings live in RAM and are gone after every power-off), keeps the state of charge, decides when the robot is on, switches the CM5's 5 V on the carrier, drives the e-stop line, and reports on CAN (`protocol/README.md`, power board section). Parts in `hardware/power-board/BOM.md`.

## States

| State | CM5 / legs | Leaves when |
|---|---|---|
| boot | as they were | BMS set up: button held or pack already on → on; USB-C in → charge; neither → off. BMS silent for 2 s → fault |
| charge | CM5 off; the side boards get VBAT but their servo bucks stay off | button press → on; no USB-C for 5 s → off |
| on | on | long press (2 s), key 40, low battery (a cell under 3.3 V or SoC under 2 % for 10 s) → halting; CM5 halted on its own → off / charge |
| halting | on, SHUTDOWN_REQ_N low | HALTED for 1 s, 30 s timeout, or a second long press → off / charge |
| off | FETs open, SoC saved | sends SHUTDOWN once the button is released (TS2 low would wake it straight back up); USB-C keeps the BMS awake → charge |
| fault | CM5 off | retries the BMS every 5 s |

An MCU reset (watchdog, CAN update) finds the BMS configured and the FETs closed and carries on without touching them; the CM5's 5V_EN is pulled on in hardware, so the CM5 doesn't notice.

E-stop: while ROS sets the e-stop flag in SYNC (on and halting), the MCU pulls ESTOP_N low, and a diode on every leg cell holds its servo buck off. A stale SYNC lets go: the legs crouch and power down on their own then.

The gauge starts from the resting cell voltage (or the SoC saved at power-off if the two agree within 15 %), then follows the BMS coulomb counter; "charge done" from the BQ25798 sets 100 %. Capacity is key 32 (default 8000 mAh). The charger is fed every second: if its 40 s watchdog runs out it falls back to the PROG defaults (4S, 1 A), and the next poll writes the settings back.

Cell temperature: with a thermistor on J-NTC (DIY pack) set key 37 to 1 and save; it applies at the next power-up, since reconfiguring the BMS opens the FETs. The default, 0, leaves TS1 unused and lets the BMS die temperature stand in: a drone pack has no thermistor, and an open TS1 reads as deep cold and trips the undertemperature protection.

## What the board has to match

- **BQ7694202PFBR, not BQ76942PFBR.** The plain part boots with REG1 off, and REG1 is what enables the MCU's 3.3 V buck. The 02 variant has REG1 on at 3.3 V and I2C CRC on (the driver does the CRC).
- The 3.3 V buck runs from the pack side of the FETs: the MCU has to be up before they close.
- Cells on VC1, VC2, VC3 and VC10 (TI: cells 1, 2 and 10 must be real), VC4–VC9 shorted to VC3. Vcell Mode 0x0207.
- Thermistors (10k, 18k pull-up model): TS1 to J-NTC, TS3 at the FETs. TS2 is for the wake button and the USB-C wake FET only. HDQ unused.
- BQ25798, single input: VAC1 and VAC2 tied to VBUS, ACDRV1/2 to GND. No NTC: TS gets a divider from REGN that reads as 25 °C, and the firmware sets TS_IGNORE. VAC_OVP stays at 26 V: the other steps are 18, 12 and 7 V.
- The carrier's 5 V buck EN is pulled up there; the 2N7002 on PB0 (100k gate pull-down) pulls it low.
- HALTED (J-SYSCTL pin 6) needs a 100k pull-down: the CM5 pin floats until Linux halts.

## Pins (LQFP32)

| Pin | Function | |
|---|---|---|
| PA11, PA12 | FDCAN1 | TCAN332 |
| PB6, PB7 | I2C1 | BQ7694202 (0x08) and BQ25798 (0x6B), 400 kHz, 2.2k pull-ups to 3V3 |
| PB0 | CM5_OFF | 2N7002 on the carrier's 5V_EN (J-SYSCTL pin 7) |
| PA8 | ESTOP_N, open drain | through 100 Ω to J-SYSCTL pin 4 (the carrier passes it on to both J-CAN); read back on the same pin |
| PA9 | SHUTDOWN_REQ_N, open drain | J-SYSCTL pin 5 |
| PA0 | BUTTON, pull-up | on the button; the button wakes TS2 through a BAT54J, so the USB-C wake FET never reads as a press |
| PA1 | HALTED | J-SYSCTL pin 6 |
| PA6 | 5V_PG | J-SYSCTL pin 8, the carrier buck's PG |
| PB1 | BMS_ALERT | wired, not used yet |
| PB2 | CHG_INT | wired, not used yet |
| PA15 | LED | |
| PA13, PA14, NRST | SWD | TC2050 |

LED: on = running (a short blink off every second on low battery), slow blink = charging, steady while charging is done, fast blink = halting, flicker = fault.

## Build and test

```sh
cmake -S firmware/power-node -B build/power-host && cmake --build build/power-host && build/power-host/test_power
cmake -S firmware/power-node/stm32 -B build/power-stm32 [-DBOARD=nucleo] && cmake --build build/power-stm32
```

On the Nucleo, `-DNUCLEO_CAN_PA11=ON` moves CAN to the power board's pins, PA11/PA12, wired to PD0/PD1 on the morpho header for the on-board transceiver.

`test_power` runs the real logic against register-level models of both TI chips (CONFIG_UPDATE, checksums, CRC, FET control, CUV, coulomb counter, SHUTDOWN, the charger watchdog). The register addresses come from the BQ76942 TRM (SLUUBY1B) and the BQ25798 datasheet (SLUSDV2C); on the bench, key 39 reads any BMS setting back to check it.

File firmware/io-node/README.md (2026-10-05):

# IO node

The STM32C092KCT6 on the CM5 carrier (U601, sheet `io_mcu`). It takes the slow serial devices off the CM5 and talks to it over one UART: ExpressLRS (CRSF), the LDS01RR lidar (Roborock vacuum part), the MAX-M10S GNSS, the RFM95W LoRa module, battery / 5 V / NTC sensing, the buzzer and the LTE supply. It also sends a LoRa position beacon on its own, so the robot can be found with the CM5 down.

Runs on the 48 MHz HSI (no crystal, no CAN), linked at the start of flash without the CAN bootloader. Logic in `src/`, tested on the PC (`test/test_io.c`, with a simulated SX1276 in `sim/`); `stm32/` holds the drivers (register-level UARTs, SPI, ADC and timers) and the pin map.

```sh
cmake -S firmware/io-node -B build/io && cmake --build build/io && ctest --test-dir build/io
cmake -S firmware/io-node/stm32 -B build/io-stm32 && cmake --build build/io-stm32
```

## Pins

| Pin | Port | Use |
|---|---|---|
| 19, 21 | PA9, PA10 | USART1 to the CM5 (GPIO4/5, its UART2), 1 Mbaud; ROM bootloader |
| 9, 10 | PA2, PA3 | USART2 to the ELRS receiver, CRSF 420 kbaud |
| 8 | PA1 | USART4 RX from the LDS01RR, 115200 baud (XV-11 protocol) |
| 32, 1 | PB8, PB9 | USART3 to the MAX-M10S, 9600 baud NMEA |
| 2 | PC14 | GNSS PPS (input, unused for now) |
| 16 | PB1 | TIM3_CH4, lidar motor PWM at 30 kHz (low-side FET, motor from 5 V) |
| 11 | PA4 | TIM14_CH1, buzzer |
| 26–29 | PA15, PB3–5 | RFM95W NSS, SCK, MISO, MOSI (SPI1, 6 MHz) |
| 23, 22, 20 | PA12, PA11, PC6 | RFM95W NRST, DIO0, DIO1 |
| 7, 13, 14 | PA0, PA6, PA7 | ADC: VBAT (100k/22k), 5 V (10k/10k), NTC (10k pull-up, B 3380) |
| 15, 17 | PB0, PB2 | LTE_EN (TPS62933), LTE_STATUS |
| 3 | PC15 | LED: 1 Hz with the CM5 talking, 4 Hz without |

## Link to the CM5

UART2 on the CM5 (`dtoverlay=uart2-pi5`, `/dev/ttyAMA2`), 1 Mbaud 8N1. A message is a type byte, the payload and a CRC-16/CCITT-FALSE (poly 0x1021, init 0xFFFF, little endian) over both, COBS-encoded and ended with 0x00. Payload up to 250 bytes; numbers little endian. The ROS side is `vector_io/link.py`.

| Type | Direction | Payload |
|---|---|---|
| 0x01 STATUS | to CM5, 10 Hz | u32 firmware, u32 uptime ms, u8 reset cause, u8 flags, u16 VBAT mV, u16 5 V mV, i16 NTC 0.1 °C (-32768 = open/short), u8 sats, u8 fix quality, u16 beacons sent, u16 messages dropped, u16 bad CRSF / lidar / NMEA / link |
| 0x02 CRSF | to CM5 | a CRSF frame, sync to CRC |
| 0x03 LIDAR | to CM5 | an XV-11 packet, 22 bytes: 0xFA, index 0xA0–0xF9 (4° each), speed in 1/64 rpm, 4 × (distance mm, bit 15 invalid; strength), 15-bit checksum |
| 0x04 NMEA | to CM5 | a sentence, `$` to the checksum |
| 0x05 LORA_RX | to CM5 | i16 RSSI dBm, i8 SNR × 4, the packet |
| 0x06 LORA_TX | to CM5 | u8 result of a LORA_SEND: 0 sent, 1 busy, 2 duty-cycle wait, 3 no radio |
| 0x81 CRSF_OUT | to IO | a CRSF frame for the receiver (telemetry) |
| 0x82 LIDAR_RPM | to IO | u16 motor speed in rpm (180–349 gives data; 300 = 5 turns/s), 0 = off |
| 0x83 BEEP | to IO | u16 Hz, u16 on ms, u16 off ms, u8 count (0 stops) |
| 0x84 LTE_POWER | to IO | u8 on |
| 0x85 LORA_SEND | to IO | up to 64 bytes |
| 0x86 BEACON | to IO | u16 interval in s, 0 = off (default 30) |
| 0x87 BOOTLOADER | to IO | u32 0x746f6f62 ("boot"): reset into ST's ROM bootloader |

Status flags: bit 0 LTE_EN, 1 LTE_STATUS, 2 RC channels in the last 0.5 s, 3 lidar packet in the last 0.5 s, 4 NMEA in the last 2 s, 5 GGA fix, 6 RFM95W found, 7 a message from the CM5 in the last 2 s.

## Lidar

The LDS01RR's motor is the host's to drive: the IO MCU starts it at 60 % duty, then holds the asked speed with a PI loop on the speed field of every packet (about 2 s to settle, ±1 rpm). The motor is off until the CM5 sends LIDAR_RPM, so it doesn't spin with Linux down.

## LoRa

869.525 MHz (g3 sub-band, 10 % duty cycle), SF9, 125 kHz, CR 4/5, CRC on, sync word 0x12, 14 dBm. After every packet the radio stays quiet for 9× its air time. The beacon is 16 bytes (165 ms on air): `'V'`, u8 sequence, u8 fix quality (0 = last known position), u8 sats, i32 lat × 1e7, i32 lon × 1e7, i16 altitude m, u16 VBAT in 10 mV. Any RFM95W or SX127x with the same settings receives it.

## Flashing

First time over the TC2050 (J601) with `stm32c0/flash_swd.sh`, or from the CM5 over SWD by closing JP601–JP603. After that from the CM5 over the link: `vector_io` sends BOOTLOADER, the MCU resets into the ROM bootloader on USART1, and `stm32flash` writes the image:

```sh
ros2 run vector_io io_flash.py build/io-stm32/io-node.bin
```

The ROM bootloader also listens on USART2, where the ELRS receiver sends CRSF; stm32flash's 0x7F on USART1 normally wins, but if it doesn't, unpower the receiver for the flash (open JP604, or JP605 if it runs on 3.3 V).

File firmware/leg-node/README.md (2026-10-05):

# Leg node firmware

One STM32C092KCT6 (LQFP32) per leg cell. The leg logic is plain C in `src/` with the hardware behind `hal.h`, so the same code runs on the chip, in the unit tests and in `sim_legs` (six legs with simulated servos on SocketCAN).

## Pins

From `stm32/leg-node.ioc`, checked by loading it in CubeMX 6.18. Labels match the side-board schematic.

| Pin | Port | Function | Label |
|---|---|---|---|
| 2, 3 | PC14, PC15 | HSE crystal, 40 MHz (same part as the MCP251863 on the carrier) | |
| 7 | PA0 | ADC1_IN0 | ADC_POT_COXA |
| 8 | PA1 | ADC1_IN1 | ADC_POT_FEMUR |
| 9 | PA2 | ADC1_IN2 | ADC_POT_TIBIA |
| 10 | PA3 | ADC1_IN3 | ADC_I_LEG (INA181 out) |
| 11 | PA4 | ADC1_IN4 | NTC_SENSE |
| 12 | PA5 | ADC1_IN5 | ADC_VBAT (100k / 15k) |
| 13 | PA6 | ADC1_IN6 | ADC_6V0 (15k / 10k) |
| 18 | PA8 | TIM1_CH1 | TIM_PWM_COXA |
| 19 | PA9 | TIM1_CH2 | TIM_PWM_FEMUR |
| 21 | PA10 | TIM1_CH3 | TIM_PWM_TIBIA |
| 22 | PA11 | FDCAN1_RX | |
| 23 | PA12 | FDCAN1_TX | |
| 24 | PA13 | SWDIO | |
| 25 | PA14 | SWCLK | |
| 30 | PB6 | I2C1_SCL | TOF_SCL |
| 31 | PB7 | I2C1_SDA | TOF_SDA |
| 15 | PB0 | out | BUCK_EN |
| 16 | PB1 | in | BUCK_PG |
| 17 | PB2 | in | GPIO_ESTOP (low = stop) |
| 27 | PB3 | in, pull-down | LEG_ID_B0 |
| 32 | PB8 | in, pull-down | LEG_ID_B1 |
| 1 | PB9 | in, pull-down | SIDE_BIT |
| 28 | PB4 | – | not connected |
| 29 | PB5 | out | TOF_XSHUT, not on the side board's J-TOF |
| 26 | PA15 | out | LED |
| 6 | PF2 | NRST | |

PA7 is the DBG test pad: high while each 1 ms tick runs (ToF, leg logic, LED), so a scope shows the loop time and any overrun; the pulse width should stay well under 1 ms. Spare: PC6.

Leg ID: jumpers to 3V3, read with the internal pull-downs. Two per cell give its position, bridged as B1B0 = 01 for cell A next to the CAN-in connector (leg 1), 10 for B, 11 for C at the outer end (leg 3). JP107 sets the side for the whole board: open = left, bridged = right. The right board is the same PCB turned 180°, so its cell A sits at the other end of the body and the order runs backwards: left A/B/C = L1/L2/L3 (nodes 1–3), right A/B/C = R3/R2/R1 (nodes 6/5/4). R1 is then the front leg on both sides, as in `legs.yaml`. This assumes cell A is at the front on the left side; if the chassis puts it at the rear, swap the two sides in `leg_node_from_straps()` (`src/leg_id.h`). Position 00 means the jumpers weren't set: the leg stays off with a config fault and blinks fast. `leg_config.py read` shows the raw jumpers.

Clocks: the C0 has no PLL, so the core runs from HSI48 (48 MHz, divider 1) and FDCAN from the 40 MHz crystal (20 time quanta per bit at 1 Mbit/s; 25 MHz also works, `-DSIDE_HSE=25000000`). HSI alone is ±1 %, too loose for CAN between six nodes. TIM1 runs at 1 MHz (prescaler 47, period 19999), so pulse widths are set in µs. The ADC must use a clock divider: CubeMX shows 48 MHz, above the C0's ADC limit.

The schematic still needs the ADC_VBAT and ADC_6V0 dividers, and the pot inputs changed to 10k series + 100 nF (see `docs/servos.md`).

## What the leg does

- **Off** until the CM5 sends `LEG_CMD` with enable and SYNC is running, and every joint is calibrated.
- **Wake**: buck on, then per joint: start the pulses at the measured position + 30 µs, make a 5° test move (away from whichever end of the range is near) and check the wiper moved by that much. A servo that ignores its first pulse gets sent past its position and tried again, three times, then the leg faults.
- **Active**: follows the commanded angles, slew-limited to 400°/s, clamped to the joint limits.
- **Crouch**: SYNC lost for 100 ms: moves slowly to a crouch, then off after 2 s. SYNC back during the crouch returns to active.
- **E-stop** (pin or SYNC flag): off at once, calibration and self-test included (they reply done, as failed).
- Joint settings, defaults and saving only while the servos are off: a flash erase stalls the CPU for ~30 ms.
- **Protection**, in any powered state, goes to fault with the buck off:
  - leg current above 5 A for about 500 ms (a leaky count, so short peaks and brief dips don't matter); three stalled MG996Rs draw ~7.5 A,
  - NTC at 85 °C; the leg can't wake again until it's below 70 °C,
  - buck power-good low for 20 ms.

  Overload and buck faults clear on the next enable. During calibration the sweep stops and reports failed.
- While the servos are unpowered their pots read 0 V, so the leg keeps reporting the last good angles.
- The wiper is the median of 16 samples per joint per 1 ms tick.
- Replies to every SYNC with `LEG_STATE`, every fourth with `LEG_STATUS`. Without SYNC it sends both every 50 ms so the CM5 can find it.

## Diagnostics and self-test

Leg-wide keys (joint 255, see `protocol/README.md`) give the firmware version (git hash, stamped at every build), why it last reset (the bootloader reads the RCC flags before its own restart and passes them on), CAN bus-off and dropped-frame counts, uptime, the current amp zero and the divider corrections.

The current amp's zero is learned continuously while the buck is off and subtracted while it's on. VBAT and 6V0 have a stored gain for divider tolerance.

Self-test is for a fresh board, servos optional: supplies, power-good, current amp, NTC, ToF and which servos are plugged in, one line each. `--vbat` with a meter reading stores the VBAT correction:

```sh
ros2 run vector_hw leg_config.py --channel can0 selftest all
ros2 run vector_hw leg_config.py --channel can0 selftest R1 --vbat 15.92 --save
ros2 run vector_hw leg_config.py --channel can0 read R1      # version, reset cause, errors, then the joints
```

The CAN controller only lets SYNC and frames for its own node into the receive FIFO, so the other legs' traffic costs nothing.

## Calibration mode

`LEG_CONFIG` with op `CALIBRATE` sweeps a joint (or all three) down and up in 11 steps each way, 400 ms per step, fits `mV = mid + slope × (µs − 1500)` and replies with the result. Two ranges:

- **full**: 500–2500 µs, the whole servo, for a servo on the bench or a free-hanging leg.
- **limits**: only the joint's own range, `min_deg`..`max_deg` from its centre, direction and µs/deg, plus 5°. For a servo already in the leg, where the full range would hit the frame.

From the CM5 (or a PC with a CAN adapter):

```sh
ros2 run vector_hw leg_config.py --channel can0 calibrate R1 --mode limits --save
ros2 run vector_hw leg_config.py --channel can0 push      # docs/servos.md + legs.yaml -> all legs
ros2 run vector_hw leg_config.py --channel can0 status
```

A result is rejected if the slope is outside 0.5–3 mV/µs, the fit is off by more than 60 mV, or the wiper spans less than 200 mV (servo not moving).

## Build and test on the PC

```sh
cmake -S firmware/leg-node -B build/leg-node && cmake --build build/leg-node
build/leg-node/test_leg                 # 179 checks: restart quirk, protection, config slots, self-test, e-stop, ToF
build/leg-node/test_boot                # bootloader protocol against a RAM flash
build/leg-node/sim_legs vcan0           # six legs on a virtual CAN bus, bootloader included
```

## STM32 build

`stm32/` builds the same logic for the chip: `main.c` sets up TIM1, the ADC with DMA, I2C, the two flash config pages and the watchdog, and implements `hal.h`; `board.c` has the pins and the leg ID. The rest is shared with the power board in `firmware/stm32c0/`: clocks, FDCAN (`mcu.c`), the bootloader, linker scripts, the build helper and `flash_swd.sh`. ST's HAL and CMSIS come from their GitHub repos at pinned tags (fetched by CMake). The application is about 33 KB, the bootloader 7 KB.

```sh
sudo apt install gcc-arm-none-eabi libnewlib-arm-none-eabi
cmake -S firmware/leg-node/stm32 -B build/leg-stm32 -DBOARD=nucleo -DLEG_ID=1   # or -DBOARD=side
cmake --build build/leg-stm32                                   # -> bootloader.bin, leg-node.bin
```

The first time, over SWD (ST-LINK, or the Nucleo's own), with `firmware/stm32c0/flash_swd.sh build/leg-stm32` (asks for each of the three cells in turn; `build/nucleo 1` for one chip). It erases, writes and verifies both images, then write-protects the bootloader pages 0–7 (option bytes `WRP1A_STRT`/`WRP1A_END`; the names are from the G0 and still to be checked on the C0). By hand:

```sh
STM32_Programmer_CLI -c port=SWD -e all -w bootloader.bin 0x08000000 -w leg-node.bin 0x08004000 -rst
```

After that, over CAN from the CM5 or a PC, legs off:

```sh
ros2 run vector_hw leg_config.py --channel can0 flash R1 build/leg-stm32/leg-node.bin
ros2 run vector_hw leg_config.py --channel can0 flash all build/leg-stm32/leg-node.bin
```

## Bootloader

Flash map: bootloader 0x08000000 (16 KB), application 0x08004000 (236 KB), config 0x0803F000 and 0x0803F800 (2 KB each, kept across updates). Each save goes to the slot with the older copy and bumps a sequence number; at boot the newest one with a good CRC wins, so losing power mid-save only loses that save. After bus-off the CAN controller is restarted, in the application and the bootloader. The bootloader reads the same jumpers.

- The application jumps to the bootloader on an `ENTER` frame, but only while the leg is off or faulted; otherwise it answers busy. It sets a flag in the top 16 bytes of RAM and resets.
- After any reset the bootloader listens for 200 ms, then resets into the application. So a leg with firmware that crashes early can still be reflashed: run `flash` and power-cycle the side board.
- It stays when asked to or when there's no valid image; the LED blinks fast.
- The first 8 bytes of the image (stack pointer and reset vector) are written last, after the CRC32 over the whole image checks out. An interrupted or corrupt upload leaves no runnable image, and the leg waits in the bootloader.
- One ack per 6-byte frame keeps the 3-deep FDCAN receive FIFO from overflowing while flash is busy. 33 KB takes a few seconds per leg.

| | side board | NUCLEO-C092RC |
|---|---|---|
| crystal | 40 MHz on PC14/PC15 | 48 MHz on the board |
| CAN | PA11/PA12 → TCAN332 | PD0/PD1 → MCP2562FD, standby PD2 held low |
| pots | PA0, PA1, PA2 | PA0, PA1, PA4 (PA2/PA3 are the ST-LINK serial port) |
| PWM | PA8, PA9, PA10 | same |
| LED | PA15 | PA5 (LD1) |
| leg ID | jumpers on PB3/PB8/PB9 | `-DLEG_ID=n` at build time |
| buck, e-stop, current, NTC, supply sense | wired | not there; buck always "good", readings fixed |

CAN timing comes from the crystal: the smallest prescaler with at most 25 time quanta per bit, sample point near 87.5 % (25 MHz → 25 tq, 40 MHz → 20 tq, 48 MHz → 24 tq).

LED: on = active; while off, the leg number every 3 s (short blinks = left, long = right, so R2 is two long blinks); fast blink = waking, fault or unset leg ID; double blink = calibrating or self-test; 10 Hz = waiting in the bootloader.

## ToF

`src/vl53l1x.c` is a small C port of ST's VL53L1X ultra lite driver, the one inside the SparkFun Arduino library; its init sequence, default config and timing tables are checked register by register against SparkFun's copy and Pololu's library, and `test_leg` runs it against a register model (`sim/tof_sim.c`).

I2C1 at 400 kHz on PB6/PB7; the driver polls every 5 ms. The side board's J-TOF carries only 3V3, GND, SDA and SCL, so the XSHUT drive on PB5 reaches the sensor only on a dev setup wired to it; without it the breakout's pull-up keeps the sensor on and a held bus needs a power cycle. Short mode, 20 ms budget, a reading every 25 ms. The driver is a state machine that never blocks for more than one I2C transfer (the default config goes over in 23-byte pieces): it looks for the sensor every 500 ms, brings it up, and starts over after three bus errors in a row or a second without a range, so a sensor plugged in, unplugged or browned out comes back on its own. While it waits it holds XSHUT low, which also frees a bus the sensor was holding (a glitch on the cable through the coxa), and the I2C block is reset with it. A stuck bus costs one 25 ms HAL timeout per failed transfer before that. `LEG_STATUS` carries 0 with no sensor or no reading in the last 200 ms, 65535 when nothing valid is in range.

On the Nucleo the breakout goes to the same pins on the morpho header. To check a breakout on its own first, the Pololu `VL53L1X` Arduino library's Continuous example on the Uno does the same thing.

## Nucleo bring-up

In this order; each step only needs the ones before it. `lc` is `ros2 run vector_hw leg_config.py --channel can0`.

Wiring: Nucleo CAN header to the CANable, 120 Ω at both ends. Servos from the bench supply at 6 V, grounds joined: signals to PA8/PA9/PA10, wipers to PA0/PA1/PA4. CANable up with `sudo ip link set can0 up type can bitrate 1000000`.

1. **Build and flash.** `cmake -S firmware/leg-node/stm32 -B build/nucleo -DBOARD=nucleo -DLEG_ID=1 && cmake --build build/nucleo`, then `firmware/stm32c0/flash_swd.sh build/nucleo 1`. If the option-byte step fails, flash by hand and fix the names in the script. `STM32_Programmer_CLI -c port=SWD -r32 0x08004000 8` should show `200077F0` and a reset vector in 0x0800xxxx. Once CAN works, rebuild once with `-DNUCLEO_CAN_PA11=ON` and wires PA11–PD0, PA12–PD1 on the morpho header: the same steps then run on the boards' CAN pins and alternate function.
2. **Application starts.** LD1 blinks slowly (leg off). A fast 10 Hz blink means it stayed in the bootloader: the image is missing or the jump failed.
3. **CAN.** `candump can0` shows `021` and `031` every 50 ms. Nothing: check the termination and the bit rate, and `ip -s -d link show can0` for errors. `lc status` prints L1 off, uncalibrated; `lc read L1` shows the git hash of the build and the last reset: power after a power cycle, software after `flash`.
4. **Bootloader over CAN.** `lc flash L1 build/nucleo/leg-node.bin` ends with `L1: running`. This proves the RAM flag survives the reset and the jump back.
5. **Recovery.** Erase the first application page, `STM32_Programmer_CLI -c port=SWD -e 8 -rst`: fast blink, and `candump` shows one `081` frame. `lc flash` brings it back.
6. **PWM and ADC.** `lc calibrate L1 --joint coxa` sweeps the servo on PA8. mid and slope should land within a few mV of that servo's row in `docs/servos.md` (different ADC and reference than the Uno). Then femur and tibia.
7. **Config slots.** Calibrate all three with `--save`, press reset, and `lc read L1` still shows the values. After a second save, `-r32 0x0803F000 1` and `-r32 0x0803F800 1` both read `56454732` (the config magic).
8. **Walking.** SYNC and LEG_CMD from `robot.launch.py hardware:=can can_interface:=can0`: L1 wakes (the LED goes steady) and follows. Pull the CAN cable: it crouches, then turns off after 2 s.
9. **Bus-off.** With the leg off, short CANH to CANL for a second while `candump` runs. The frames come back within milliseconds of letting go, without a reset.
10. **ToF.** Plug a breakout into PB6/PB7 with XSHUT on PB5 while it runs. Within a second, bytes 0–1 of `031` follow a hand in front of it. Unplug and replug: it comes back.

The Nucleo can't test current, temperature, supply sense, buck power-good or e-stop: they aren't wired and read fixed values. Those wait for the side board.

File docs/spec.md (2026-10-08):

# V.E.C.T.O.R. spec

Versatile Edge Compute & Terrain Observation Robot. An 18-DOF hexapod built as an open research platform: a smart controller per leg on CAN, a CM5 carrier, a camera and SDR payload, and ELRS / Wi-Fi / 4G links. Entry for the PCBWay 9th Project Design Contest (Robotics), deadline 2027-01-24.

The main idea is "Sentinel Stance". The robot walks to a spot, lowers its body to the ground and cuts power to all servos. It then sits there for hours as a low-power sensor node (camera, SDR, GNSS, 4G). To get up again it powers the legs one at a time, starting each servo at the angle it actually measures, so nothing jerks.

Constraints: low budget. PCBs and stencils come from PCBWay and I assemble them myself. All mechanical parts are printed (PETG, TPU feet) and designed in Fusion 360. ICs come from Mouser.

Already on hand: CM5 (Wi-Fi, 8 GB eMMC), Pi 5 + AI HAT+ 2, 18× MG996R, AD9363 SDR (2T2R), HackRF, Pi CSI camera, a USB camera, 18650 cells from e-scooter packs, a spot welder, GX-12 connectors, a CANable, MCP2515 modules, 2 CH32V003 dev boards.

## Boards

Four designs, five boards:

| Board | Qty | Layers | Main parts |
|---|---|---|---|
| Side board | 2 | 4 | 3 leg cells, each with STM32C092, TCAN332DR, TPS56A37 6 V buck |
| Power & BMS | 1 | 4, 2 oz | BQ7694202, BQ25798 (USB-C), STM32C092 |
| CM5 carrier | 1 | 4, impedance-controlled | CM5, 5 V buck (TPS56A37), M.2, MCP251863, STM32C092 IO MCU, LoRa, A7670E LTE and GNSS (own sheets), IMU |
| Nose board | 1 | 2 | VL53L8CX front ToF, MMC5983MA compass, Pi camera mount |

```
[120Ω] L3 ─ L2 ─ L1 ── CM5 carrier ── R1 ─ R2 ─ R3 [120Ω]      one CAN bus, 1 Mbit/s
       └ side board L ┘      │         └ side board R ┘
                       power board (stub)

power board ──VBAT──► side L, side R, carrier (3× XT30; the carrier makes its own 5 V)
carrier ──J-NOSE (I2C, 3V3) + CSI ribbon──► nose board
```

### Side board (×2)

Both sides use the same PCB, rotated 180°, at most 100 mm long. Each side board carries three independent leg cells, and the CAN bus between those cells is just traces. A leg cell has:

- **MCU:** STM32C092KCT6 (LQFP32) with a 40 MHz crystal for FDCAN (the same part as the carrier's MCP251863); the core runs from the internal 48 MHz. It has FDCAN in hardware and a factory CAN bootloader. Pin map in `firmware/leg-node/README.md`.
- **CAN transceiver:** TCAN332DR (SOIC-8), a 3.3 V-only part.
- **Servo buck:** TPS56A37RPAR (28 V in, 10 A, 3×3 mm HotRod QFN) set to 6.0 V, switched by the MCU through EN. Three servos near stall draw about 7.5 A.
- **Current sense:** one 10 mΩ shunt and an INA181 for the whole leg. The load on each joint comes from the pot error (commanded minus measured angle).
- **Position:** the MG996R pot wiper goes into the ADC through a series resistor and RC filter (about 10k + 100 nF). Measured 15.2 mV and 11.1 µs per degree, linear over 400–2600 µs (0.13–3.14 V, about 198°), the same at 5 V and 6 V supply. No divider: the joints stay within about ±80° (≤ 2.85 V); past 3.3 V the reading just saturates and the 10k limits clamp current to well under the STM32's injection limit. Firmware treats readings above ~3.2 V as "out of range", not an angle. Resolution checked: a 12 µs (1°) step shows as a clean 10 mV change. It carries ~200 mV of spikes from the servo's own electronics, so average many samples. Always restart the PWM at the measured position: this MG996R ignores commands if the first pulse after a stop is well below where it sits.
- **PWM:** the outputs are tri-stated before power-off, otherwise the servo gets back-powered through the signal pin.
- **ToF:** a VL53L1X on its own I2C bus, so there's no address clash (2.54 mm header 1×04: 3V3, GND, SDA, SCL). The sensor sits on a breakout on the tibia, facing out in front of the leg; pinout in `interfaces.md`.
- **Protection:** a fuse or PTC per cell, an NTC at the buck, VBAT and 6 V rail sensing.
- **Leg ID:** three solder jumpers to 3V3 per cell, read as GPIOs with pull-downs: two give the cell's position on the board, one (shared by the board) the side. Details in `interfaces.md`.
- **SWD:** pads for debugging and recovery.

Shared on the board: an XT30 input, a low-Iq 3.3 V buck (stays on in Sentinel), CAN in/out on JST-XH, and a termination jumper at the outer end.

About 24 MCU pins in total: 3 PWM, 8 ADC, 3 CAN, 1–2 oscillator, 2 ToF, 3 SWD/NRST, 3 buck control/LED. Check the fit in CubeMX before layout.

### Power & BMS board

Battery protection, USB-C charging and soft power, with a power MCU on CAN. BOM in `hardware/power-board/BOM.md`.

- **Pack:** detachable, XT60 for power plus one 5-pin JST-XH balance plug (GND, C1–C4), as on drone packs, so a store-bought 4S LiPo also fits and a hobby balance charger is a backup. The 30 A fuse sits in the pack lead. Plugging the pack in doesn't spark: the BMS FETs start open.
- **BQ7694202 battery monitor** (the 02 variant has REG1 on from the factory, which starts the MCU): two high-side FETs (BSC010N04LS), so every board keeps a common ground. Cell over- and undervoltage, overcurrent and short circuit, temperature, balancing and coulomb counting. Its pre-discharge path is the inrush limit for the side boards and the carrier.
- **BQ25798 charger, USB-C only:** single input, no input FETs. A CYPD3177 asks a PD charger for 20 V, about 60 W (2.5 h); a 5 V-only source still charges at about 15 W. Plugging USB-C in wakes the BMS. The robot's load does not go through the charger.
- **No hot-swap controllers, no 5 V buck:** VBAT goes straight from the BMS FETs to both side boards and the carrier over XT30s. The 5 V buck is on the carrier; the power board switches it with 5V_EN in J-SYSCTL.
- **Soft power:** no switch in the 20 A path. Off means the BMS is in SHUTDOWN (about 1 µA, safe for months). A press on the power button (or plugging USB-C in) wakes it through TS2; REG1 enables the 3.3 V buck for the MCU, which configures the BMS and closes the FETs. A charger alone only charges, with 5V_EN held low so the CM5 stays off. A long press, low battery or a command from ROS asks the CM5 to shut down over J-SYSCTL (`gpio-shutdown`), waits for HALTED (`gpio-poweroff`, 30 s fallback), then opens the FETs and puts the BMS in SHUTDOWN, which also removes the MCU's own supply. A clean halt matters with the CM5 on microSD.
- **E-stop, no mushroom button:** stops come from ROS, the ELRS switch or the operator page, as the e-stop flag in SYNC. The power MCU then pulls ESTOP_N low from an open-drain pin, and a diode on every leg cell holds its servo buck's EN low: servo power is gone without any leg firmware. The CM5 stays up. If the CM5 or the power MCU hangs, SYNC stops and every leg crouches and powers down on its own.
- **MCU:** an STM32C092 (node 7) configures the BMS and charger at every start (their settings live in RAM), runs the power states, keeps the state of charge and reports on CAN. See `firmware/power-node/README.md`.

### CM5 carrier

- **CM5:** CM5 Lite, 2 GB, Wi-Fi, booting from a microSD socket on the carrier (more space than eMMC). 2 GB is enough, measured on a Pi 5 2 GB: the control stack (ros2_control, gait, monitor, foxglove_bridge) in Docker uses 481 MB system-wide, leaving 1.5 GB for camera and inference; H.264 in software costs 20 % of a core at 640×360 / 15 fps.
- **M.2 M-key 2242 on the single PCIe lane:** kept only as an upgrade path for a Hailo accelerator. Not fitted on the prototype or the CM5 board; vision runs on the CPU.
- **5 V for the CM5:** a TPS56A37 (the side boards' servo buck, set to 5.0 V) fed with VBAT over an XT30 from the power board. EN is pulled up on the carrier and pulled low by the power board (5V_EN in J-SYSCTL); PG goes back as 5V_PG. Without a power board, 12–16.8 V on the XT30 just runs it, which is how it's powered on the bench.
- **CAN:** MCP251863 (MCP2518FD plus transceiver in one package), which shows up as `can0` through the mainline `mcp251xfd` driver. The bus passes through the carrier, with no termination on it.
- **LTE:** SIMCom A7670E on UART4, on its own sheet. Either the module is soldered down (3.8 V from a TPS62933 on VBAT, switched by the IO MCU so a hung modem can be power-cycled; nano-SIM; U.FL for LTE and GNSS; a TXS0104E for the 1.8 V UART, DTR and STATUS; PWRKEY through a transistor; the module's GNSS looped into its UART3, so NMEA comes over the AT port) or a ready A7670E board plugs into a 1x07 2.54 mm header (GND, RXD, TXD, PWRKEY, VCC, GND, SLEEP). The whole sheet is DNP on the prototype; the pads stay. The GNSS variant of the module (A7670E-LASE, check before ordering) is the second GNSS.
- **GNSS:** on its own sheet, on a UART of the IO MCU, time pulse also to a CM5 GPIO. Either a u-blox MAX-M10S soldered down (LNA and SAW filter inside, which matters because LTE band 3 uplink sits close to GPS L1; the active antenna is fed from its VCC_RF) or a ready GNSS module on a 1x04 2.54 mm header (GND, RX, TX, VCC). Two solder bridges pick the header's supply, 3.3 V closed and 5 V open by default, since many GNSS boards take either; 1k series resistors on RX/TX keep a 5 V board from driving the STM32 hard. The sheet is DNP on the prototype; the pads stay. The second GNSS is the one in the LTE module.
- **Nose board connector (J-NOSE):** 3V3 and I2C for the front sensors, plus the CSI connector for the camera ribbon. On the nose board it is J1 on the back; J2 on the front shares its pads as an alternative, fitted instead of J1 with a reversed cable. An I2C header for an external compass stays as a fallback.
- **SDR:** RJ45 to the AD9363 over GbE. That gives far more bandwidth than its USB 2.0 port.
- **IMU:** ST LSM6DSV16X on the CM5's I2C1, interrupt on a GPIO.
- **IO MCU:** an STM32C092, the same part as the leg cells and the power board, takes the slow serial devices off the CM5, which has only five UARTs on fixed pins. It talks to the CM5 over UART2 at 1 Mbaud and handles ELRS (CRSF, 420 kbaud), the lidar (115.2 kbaud in, motor PWM out), the GNSS and the LoRa radio, plus the ADC housekeeping (VBAT, 5 V rail, board temperature), a buzzer, and the LTE module's power switch and STATUS. That's about 35 kB/s in total, a third of the link. It also keeps the LoRa position beacon going if Linux hangs.
- **LoRa:** a telemetry link next to ELRS: robot state and GNSS position at a low rate, so the robot can be found even with Wi-Fi and LTE down. It runs on 869.525 MHz (g3 sub-band, 10 % duty cycle, SF9 / 125 kHz): the 16-byte position beacon takes 165 ms on air and goes every 30 s. The radio is a HopeRF RFM95W (SX1276, 3.3 V) soldered to the carrier on the IO MCU's SPI (DIO0 and DIO1 as interrupts), with a U.FL for the 868 MHz antenna. The Elecrow LR1262 modules on hand (STM32WLE5 with AT firmware over UART) suit the ground side: SX126x and SX127x talk to each other with the same spreading factor, bandwidth, coding rate and sync word.
- **Other connectors:**
  - 2× USB-A behind current-limit switches
  - 2× CSI, 22-pin FFC: CAM0 is the main camera, CAM1 is for a second one (I2C on ID_SC/ID_SD, 2.2k pull-ups)
  - microSD socket (the CM5 Lite boots from it)
  - ELRS and lidar connectors, both on the IO MCU. The lidar is an LDS01RR from a Roborock vacuum (Neato XV-11 protocol, 360 points per turn, 0.15–6 m): its motor is driven by the IO MCU through a low-side FET and held at 300 rpm from the speed in its packets. On the carrier: J-LIDAR (JST-XH 4-pin: 5 V, GND, lidar TX into the MCU through 1k, lidar RX unused) and J-LIDARMOT (JST-XH 2-pin: +5 V and the drain of Q602, an SI2302-TP logic-level N-FET (AO3400A fits the same footprint), gate from PB1 through 1k with 100k to GND, B5819W Schottky across the motor). The lidar's own plugs are JST-PH 2.0, so it needs an adapter cable. ELRS gets the same supply bridges as the GNSS header, 5 V closed by default: most receivers want 5 V, some run from 3.3 V. The lidar is 5 V only and the LoRa module 3.3 V only, so they get no bridges.
  - a USB-C port for rpiboot, data only: D+/D− to the CM5's USB 2.0, 5.1k on CC, VBUS not connected to the 5 V rail (the CM5 is powered from VBAT, or a bench supply on the XT30). With a CM5 Lite on microSD it's rarely needed
  - an nRPIBOOT jumper and a 1x3 2.54 mm console UART header (GND, TX, RX)
  - a fan header: 4-pin 2.54 mm footprint (5 V, PWM, GND, tach), not fitted until the fan is chosen
  - an RTC battery
- **SWD recovery header:** on CM5 GPIOs.
- **Antennas:** all go to a printed plate on top via U.FL pigtails, with GNSS as far from LTE as possible.

CM5 UARTs: console, IO MCU, LTE; UART3 is spare. GPIO allocation in `docs/interfaces.md`.

### Nose board

A small 2-layer board in the nose cone, looking forward through an opening in the shell. It carries the sensors that need to see ahead or stay away from the power wiring:

- **VL53L8CX front ToF** (8×8 zones, up to ~4 m, 1–2 m in direct sun, 65° diagonal FoV), soldered directly: the chip is 35 RON against 150+ for a breakout. It gives measured distance to what the camera sees. The VL53L9CX (54×42 zones over MIPI CSI) was considered: far better data, but no Pi 5 / CM5 driver yet and about 8× the price, so it stays a possible upgrade.
  - Supplies: AVDD 3.3 V from the carrier (43–50 mA ranging), CORE_1V8 and IOVDD from one 1.8 V LDO (TLV75518P class, ≥ 150 mA). IOVDD can't be 3.3 V.
  - Level shifting to the CM5's 3.3 V: PCA9306 on SDA/SCL (2.2k to 1.8 V on the sensor side), a BSS138 each on LPn and INT.
  - Straps for I2C: SPI_I2C_N and NCS 47k to GND, 47k pull-ups on INT, LPn and SYNC, MISO open, RSVD1–3 and the thermal pad to GND.
  - LPn goes to a CM5 GPIO so the sensor can be restarted. Keep ST's protective film on the lens while soldering; no printed plastic in front of it, only an opening at least as wide as the exclusion cone.
- **MMC5983MA compass,** moved here from the carrier: the nose is the point furthest from the servo, buck and LTE currents. Same I2C bus (0x30, the ToF is 0x29).
- **Pi camera mount:** the camera module screws onto the nose board (standard Pi camera hole pattern), next to the ToF with parallel optical axes. That makes the camera–ToF transform fixed by the PCB instead of a printed part, so the ToF zones can be fused with the camera: each YOLO box takes its measured distance from the zones in its direction. The ribbon goes straight to the carrier's CSI connector.
- A status LED (and room for a small buzzer, a "robot about to move" warning).

The IMU stays on the carrier near the body's centre, where rotation doesn't add acceleration.

**Compass placement.** A wire carrying 10 A makes about 40 µT at 5 cm, which is close to Earth's field here (~48 µT). Fixed iron calibrates out; changing currents don't. So:
- keep it at least 5 cm from inductors, the LTE module and the fan
- no high-current copper under it
- twist all the power pairs
- use brass or nylon screws nearby
- calibrate with the servos powered

In Sentinel Stance the legs are off, so the compass is at its cleanest exactly when heading matters. While walking it gets fused with GNSS course and the gyro.

## Bus and flashing

Classic CAN at 1 Mbit/s. SYNC, commands and state for six legs at 200 Hz plus status at 50 Hz measure about 32% bus load on vcan. The message layout is in `protocol/vector.dbc`: `ID = (function << 4) | node`, nodes 1–6 are legs L1–R3, 7 is the power board.

CAN was picked over RS-485 for its hardware CRC, retransmit and arbitration. A babbling node goes bus-off on its own, and SocketCAN tooling is good. The CH32V003 was dropped because it has no CAN, only 16 KB / 2 KB of memory, and no practical way to flash it from Linux.

Every leg has a heartbeat watchdog. If the bus goes quiet, it crouches under control and then cuts its servos. A second bus wouldn't help: losing a side stops the walking anyway.

All MCUs get flashed from the CM5:
1. **Normal:** our own 7 KB CAN bootloader (CAN IDs from the leg ID, CRC-checked image, 200 ms listen window after reset); `leg_config.py flash` does one leg or all of them. ST's OpenBootloader was dropped: it's larger and doesn't know the leg ID.
2. **Fallback:** the factory FDCAN ROM bootloader (AN2606/AN5405), one node at a time.
3. **Recovery:** SWD through OpenOCD's `linuxgpiod` driver on CM5 GPIOs. No ST-LINK needed.

## Power and weight

- **Pack:** 4S3P from the scooter cells. Test capacity and internal resistance on every cell and match the parallel groups. 3P keeps a 20 A peak at about 7 A per cell. Expect ~130 Wh and ~570 g.
- **Series links:** use 0.2 mm pure nickel, doubled, or nickel-plated copper. Never nickel-plated steel.
- **Walking:** 40–70 W for the servos, 12–18 W for the rest.
- **Sentinel:** 9–15 W, so about 9–14 h.
- **Weight:** about 3 kg all-up. With the CAD legs (femur 67.6, tibia 118.6 mm) and the stance in `legs.yaml` (108 mm reach, 100 mm hip height), `gait_report` puts the static worst case at 7.4 kg·cm per femur servo walking forward and 8.3 sideways, up to about 75% of the MG996R's stall; standing takes 2.9.
  - The reach sets the femur torque, so keep the feet close in; the frame is where to save weight.

## Software

**MCU firmware.** CubeMX generates a CMake project, built with arm-none-eabi-gcc and edited in VS Code, bare-metal on LL/HAL. Zephyr is overkill for a 1 kHz loop with a fixed CAN schedule.

The leg loop runs at 1 kHz: PWM out, ADC in, soft-start, VL53L1X read, watchdog.

**CM5 / Pi 5.** Raspberry Pi OS, with ROS 2 Jazzy in Docker. The same images run on the Pi 5 and the CM5. It's split in three:

1. **`libvector`:** plain C++ with no ROS in it (kinematics, gait, leg state machine, CAN encoding generated from the DBC). Unit-tested on the desktop.
2. **One real-time process:** the ros2_control hardware interface over SocketCAN plus the gait controller, at 200 Hz on an isolated core with SCHED_FIFO. Safety doesn't depend on its timing.
3. **Normal ROS nodes for everything else:**
   - `robot_localization` (MAX-M10S and the LTE module's GNSS, compass, IMU)
   - ToF ray mapping
   - perception
   - a link manager (ELRS > Wi-Fi > LTE; on total loss, stop and go into Sentinel)
   - BMS, teleop

**Remote access.** Tailscale on Wi-Fi and LTE. The UI is Foxglove through `foxglove_bridge`. Don't run DDS over LTE; if several hosts ever need ROS traffic, use `rmw_zenoh`.

**Vision.** The camera (CSI) runs on the host and hands raw frames to the vision container. YOLO26n runs on the CPU from an ONNX export with ONNX Runtime (no PyTorch on the robot); measured on a Pi 5: segmentation at 320 px 12 fps, detection at 480 px 7 fps, about 150 MB. It publishes detections and the class mask into ROS, and the annotated video goes to MediaMTX as RTSP and WebRTC for the operator. The camera is for obstacle avoidance; position comes from GNSS.

**Navigation.** All testing happens outdoors, so GNSS (plus the compass) is the primary sensor, and there's no loop-closing SLAM.
- Position: leg odometry and the IMU gyro fused with GNSS in `robot_localization` (`navsat_transform` for the GNSS side).
- Missions: GPS waypoints sent over LTE; a small waypoint follower first, Nav2 only if memory allows.
- Obstacles: a local costmap around the robot. The segmentation mask is projected onto the ground using the camera pose (leg angles plus IMU tilt); YOLO boxes give an object's distance from where their bottom edge meets the ground; the leg ToF rays add true 3D points near the feet; the nose board's VL53L8CX gives measured distance ahead, fused with the camera mounted on the same board.
- A YOLO-seg model fine-tuned for trail vs not-trail (RELLIS-3D, RUGD, own footage) comes later; COCO classes cover people, vehicles and animals first.
- The robot walks at 5–15 cm/s, so 5–10 fps of perception is enough.

**ToF on the legs.** Each sensor sits on its tibia, 51 mm below the knee, looking outward and about 10° down when standing, so it sees whatever is in front of that leg. The pot feedback gives its exact pose, and as the legs step the six rays sweep up and down over the ground ahead: steps, gaps and obstacles show up before a foot lands. It's too sparse for SLAM and weak in direct sun; that's what the lidar is for.

The cable crosses the femur and tibia joints, so route it along the femur with slack at both, and keep it short for the 400 kHz I2C.

## Development setup

- 2× NUCLEO-C092RC (ST-LINK and a CAN transceiver on board)
- my CANable on the Pi 5, flashed with candleLight so it shows up as `can0`, same as the carrier
- MCP2515 modules as a fallback:
  - their 8 MHz crystal limits them to 500 kbit/s
  - power the MCP2515 at 3.3 V, or it puts 5 V on the Pi's GPIOs
- VL53L1X and INA181 breakouts
- the CH32V003 boards, for early servo and pot tests

Bring-up order:
1. Pi 5 plus the Nucleos, with one modded servo.
2. One side board on a bench PSU.
3. The whole robot on the bench PSU.
4. The power board and the battery.
5. The CM5 carrier replaces the Pi 5.

## Plan

| Weeks (from 2026-09-28) | |
|---|---|
| 1–2 | Frame CAD and weight budget, servo and pot measurements, cell tests, leg firmware on a Nucleo, side board schematic |
| 3 | Side board rev A to fab, power board schematic, URDF and gait in sim |
| 4–5 | Power board rev A to fab, carrier schematic, print the frame |
| 6–7 | Side board bring-up, walking on the bench PSU, carrier rev A to fab |
| 8–9 | Power board bring-up, walking on battery |
| 10–11 | Carrier bring-up, rev B of everything |
| 12–14 | Sentinel and wake-up, link failover, LTE/VPN, GNSS/compass, SDR and AI demos |
| 15–17 | Field tests, write-up, video, PCBWay project page |

## Open

- Side board length (depends on the chassis).
- Connector choices marked TBD in `interfaces.md`.

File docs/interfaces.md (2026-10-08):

# Interfaces (board-to-board connectors & harnesses)

Draft. Freeze everything marked TBD before starting schematics.
Both ends of a cable use the same footprint and pin order.

## Overview

| ID | From → To | Connector | Carries |
|---|---|---|---|
| J-BAT | Pack → Power board | XT60 | VBAT (≈20 A peak) |
| J-BAL | Pack → Power board | JST-XH 5-pin | Cell taps C0–C4 |
| J-NTC | Pack → Power board | JST-PH 2-pin | cell NTC (DIY pack only) |
| J-USBC | Panel → Power board | panel-mount USB-C receptacle with a pigtail to a JST-XH 6-pin on the board | PD charge input, 20 V, the only charge input; see below |
| J-PWRBTN | Panel → Power board | JST-PH 2-pin | momentary power button |
| J-LEGPWR-L / -R | Power board → Side board | XT30 (PCB: XT30PW-M) | VBAT (~13 A peak each) |
| J-SYSPWR | Power board → Carrier | XT30 (PCB: XT30PW-M) | VBAT; the carrier makes 5 V itself |
| J-USBDEV | Carrier → laptop | USB-C receptacle | CM5 USB 2.0 for rpiboot, data only |
| J-SYSCTL | Power board ↔ Carrier | JST-XH 10-pin | the power board's CAN stub and its control lines in one cable; see below |
| J-CAN (×2) | Carrier ↔ side boards | JST-XH 4-pin | CANH, CANL, GND, ESTOP_N |
| J-SERVO (×9 per side) | Side board → servo | 2.54 mm header 1×04, three per leg as a 3×4 block | GND, V+ (6 V), PWM, POT |
| J-TOF (×3 per side) | Side board → ToF | 2.54 mm header 1×04 | 3V3, GND, SDA, SCL |
| J-SWD (per MCU) | Debug | side board: 1 mm pads for PCBite probes (SWDIO, SWCLK, NRST) plus one shared 2.54 mm 1×02 (3V3, GND) per board; carrier and power board: TC2050 | SWDIO, SWCLK, NRST, 3V3, GND |
| J-SWDREC | Carrier → any MCU | 1.27 mm 2×5 | CM5 GPIO SWD recovery |
| J-ELRS | Carrier → receiver | JST-GH 4-pin | 5 V, GND, TX, RX |
| J-LIDAR | Carrier (IO MCU) → LDS01RR lidar | JST-XH 4-pin | 1 TX (lidar → MCU, 3.3 V), 2 RX (not used), 3 GND, 4 5 V; the lidar end is JST-PH 2.0 |
| J-LIDARMOT | Carrier → LDS01RR motor | JST-XH 2-pin | M+ (5 V), M− (low-side FET, PWM from the IO MCU) |
| J-LTE | Carrier → A7670E board | 1x07 2.54 mm | GND, RXD, TXD, PWRKEY, VCC, GND, SLEEP; the alternative to the soldered-down A7670E |
| J-CONSOLE | Carrier → USB-UART | 1x03 2.54 mm | GND, TX, RX (CM5 UART0) |
| J-NOSE | Carrier → nose board | JST-GH 8-pin | see below |
| J-CAM0, J-CAM1 | Carrier → cameras | Pi camera FFC (22-pin on the carrier) | CSI; CAM0 is the camera screwed to the nose board, CAM1 is spare |

Board-to-board cables are JST-XH (2.5 mm, horizontal headers). JST-GH stays only where the other end dictates it (ELRS receiver) and on J-NOSE.

## CAN bus

```
[120Ω] L3 ─ L2 ─ L1 ── J-CAN ── CARRIER (pass-through) ── J-CAN ── R1 ─ R2 ─ R3 [120Ω]
                                     │ J-SYSCTL pins 1–4, stub < 30 cm
                                POWER BOARD
```

J-CAN pinout (JST-XH 4-pin):

| Pin | Signal |
|---|---|
| 1 | CANH |
| 2 | CANL |
| 3 | GND |
| 4 | ESTOP_N: pulled up on every leg cell, only ever driven low (by the power MCU's open-drain pin); a diode on each leg cell holds its servo buck's EN low while it's low |

## J-SYSCTL pinout

JST-XH 10-pin (board: S10B-XH-A-1, horizontal) on the power board and the carrier, straight 1:1 cable. Pins 1–4 are J-CAN's, in the same order: the power board's stub off the CAN bus, plus the e-stop line. Twist CANH with CANL.

| Pin | Signal | Direction | Notes |
|---|---|---|---|
| 1 | CANH | bus | |
| 2 | CANL | bus | |
| 3 | GND | | |
| 4 | ESTOP_N | power → all | open drain from the power MCU, pulled up on every leg cell; the carrier passes it to both J-CAN pin 4 and to CM5 GPIO24, so ROS sees the hardware stop |
| 5 | SHUTDOWN_REQ_N | power → CM5 | `gpio-shutdown` overlay: low = shut down |
| 6 | HALTED | CM5 → power | `gpio-poweroff` overlay: high once halted; 100k pull-down on the power board |
| 7 | 5V_EN | power → carrier | the carrier's 5 V buck EN: pulled up on the carrier, pulled low by the power board to keep the CM5 off |
| 8 | 5V_PG | carrier → power | the 5 V buck's PG |
| 9 | GND | | |
| 10 | spare | | not connected on either board |

## J-USBC pinout

A panel-mount USB-C receptacle (power only) with a short pigtail to a JST-XH 6-pin on the power board (S6B-XH-A-1). The CYPD3177 on the board needs both CC lines, so the panel part has to bring out VBUS, GND, CC1 and CC2; a two-wire (VBUS/GND only) USB-C socket can't negotiate 20 V. VBUS and GND get two pins each (3 A, the XH limit per pin).

| Pin | Signal |
|---|---|
| 1 | VBUS |
| 2 | VBUS |
| 3 | CC1 |
| 4 | CC2 |
| 5 | GND |
| 6 | GND |

Keep the pigtail short (≤ 15 cm). The VBUS TVS sits on the board at the connector.

## J-NOSE pinout

The same numbering on the carrier and on the nose board's J1, joined by a straight 1:1 JST-GH cable.

| Pin | Signal | Nose board side |
|---|---|---|
| 1 | LED | status LED, optional; not connected on the carrier |
| 2 | MAG_INT | compass data ready, optional |
| 3 | TOF_INT | INT → BSS138 → CM5 GPIO |
| 4 | TOF_LPN | CM5 GPIO → BSS138 → LPn (sensor restart) |
| 5 | SCL | 3.3 V side of the PCA9306; the compass sits on this side |
| 6 | SDA | as SCL |
| 7 | GND | |
| 8 | 3V3 | VL53L8CX AVDD, 1.8 V LDO in, compass |

The nose board has two footprints on the same pads: J1 on the back (the one fitted) and J2 on the front, for a cable from the front instead. Only one is ever fitted. J2 is the same part flipped, so its pin 1 sits where J1's pin 8 is: it needs a reversed cable (pin 1 ↔ 8), never the straight one.

Keep the cable under ~30 cm for 1 MHz I2C.

## J-SERVO pinout

| Pin | Signal | Wire |
|---|---|---|
| 1 | GND | brown |
| 2 | V+ 6.0 V | red |
| 3 | PWM | orange |
| 4 | POT wiper | added wire (pot mod) |

## J-TOF pinout

2.54 mm header 1×04 (footprint `vector:PinHeader_1x04_P2.54mm_Vertical_Tile`), a 4-way Dupont housing on the lead, glued once it works. The pin order matches the VL53L1X breakout in use; its own pull-ups hold XSHUT high, and the firmware polls instead of using INT. PB4 and PB5 on the MCU are spare.

| Pin | Signal | Side board end |
|---|---|---|
| 1 | 3V3 | 100 nF at the connector |
| 2 | GND | |
| 3 | SDA | 2.2k pull-up to 3V3, DNP if the breakout has its own |
| 4 | SCL | 2.2k pull-up to 3V3, DNP if the breakout has its own |

## Leg ID jumpers

Each leg cell reads three solder jumpers to 3V3 as GPIOs with the internal pull-downs (bridged = 1), so the node ID comes from the board, not the firmware:

| Bit | MCU pin | Jumpers | Meaning |
|---|---|---|---|
| POS0, POS1 | PB3, PB8 | two per cell, set once on the root sheet | the cell's position: 01 = cell A (next to the CAN-in connector), 10 = B, 11 = C (outer end); 00 = not set |
| SIDE | PB9 | JP107, one per board, shared by its three cells | open = left board, bridged = right board |

The right board is the same PCB turned 180°, so its cell A sits at the other end of the body and the order runs backwards (`leg_node_from_straps()` in `firmware/leg-node/src/leg_id.h`):

| Board | Cell A | Cell B | Cell C |
|---|---|---|---|
| Left (JP107 open) | L1, node 0x1 | L2, node 0x2 | L3, node 0x3 |
| Right (JP107 bridged) | R3, node 0x6 | R2, node 0x5 | R1, node 0x4 |

The power board is node 0x7, fixed in its firmware. Position 00 keeps a leg off with a config fault; `leg_config.py read` shows the raw jumpers.

## CM5 GPIO allocation

| GPIO | Use |
|---|---|
| 0, 1 | ID_SD, ID_SC: CAM1 I2C |
| 2, 3 | I2C1 SDA, SCL: IMU, J-NOSE |
| 4, 5 | UART2 TX, RX: IO MCU, 1 Mbaud (framing in `firmware/io-node/README.md`) |
| 6 | IMU_INT |
| 7 | GNSS_PPS (time pulse) |
| 8 | SWD recovery NRST |
| 9 | MAG_INT (J-NOSE); UART3 RX if UART3 is ever needed |
| 10, 11 | SWD recovery SWDIO, SWCLK |
| 12, 13 | UART4 TX, RX: LTE |
| 14, 15 | UART0 TX, RX: console |
| 16 | CAN_INT (MCP251863) |
| 17 | LTE_PWRKEY |
| 18, 19, 20, 21 | SPI1 CE0, MISO, MOSI, SCLK: MCP251863 (SPI0 shares pins with UART3) |
| 22 | SHUTDOWN_REQ_N (J-SYSCTL, in) |
| 23 | HALTED (J-SYSCTL, out) |
| 24 | ESTOP_N (J-SYSCTL, in) |
| 25 | TOF_INT (J-NOSE) |
| 26 | TOF_LPN (J-NOSE) |
| 27 | LTE_SLEEP |

ELRS, the lidar, the GNSS and the LoRa radio sit on the IO MCU. The nose LED on J-NOSE stays unconnected.

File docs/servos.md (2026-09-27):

# Servos

18× MG996R, each with a wire soldered to the pot wiper (blue) for position feedback. Two batches: A1–B1 have the usual pot; B2 onward have a different, lower-resistance pot inside (about 30 Ω as measured), so expect their calibration to differ from the first batch.

## Names

Code and docs use L1–L3 / R1–R3 (1 front, 3 rear) and coxa / femur / tibia, e.g. `R1_coxa`.

The servos themselves carry printed labels A–F plus joint number (1 coxa, 2 femur, 3 tibia), going round the body:

| Label | Leg | Position |
|---|---|---|
| A | R1 | right front |
| B | R2 | right middle |
| C | R3 | right rear |
| D | L3 | left rear |
| E | L2 | left middle |
| F | L1 | left front |

So the servo labelled A1 is `R1_coxa`, C3 is `R3_tibia`, F2 is `L1_femur`.

## Calibration

Wiper voltage is linear in the pulse width: `wiper_mV = mid + slope × (pulse_us − 1500)`. On R1_coxa, 1000 µs of pulse is 90° of shaft rotation (0.09°/µs), so 0–180° is 500–2500 µs.

Measure with `test-tools/servo_test` on an Uno, wiper straight to A0, servo at 6.0 V: send `c R1_femur` and it sweeps 500–2500 µs and prints the row.

| Joint | Label | Date | mid (mV @ 1500 µs) | slope (mV/µs) | @ 500 µs | @ 2500 µs | fit error (mV) | noise p-p (mV) | Notes |
|---|---|---|---|---|---|---|---|---|---|
| R1_coxa | A1 | 2026-09-26 | 1646 | 1.366 | 269 | 3001 | < 15 | 190–260 | linear 400–2600 µs, 90° per 1000 µs by eye |
| R1_femur | A2 | 2026-09-26 | 1565 | 1.431 | 134 | 2996 | 20 | 620–800 | same noise with pulses stopped; about 3.5× R1_coxa |
| R1_tibia | A3 | 2026-09-26 | 1591 | 1.424 | 167 | 3015 | 16 | 390–570 | 41 mV rms, 97% above 160 Hz |
| R2_coxa | B1 | 2026-09-26 | 1593 | 1.374 | 219 | 2967 | 19 | 360–470 | 4 sweeps within 19 mV; parked past the top end it read 3.22 V |
| R2_femur | B2 | 2026-09-27 | 1522 | 1.465 | 57 | 2987 | 23 | | second batch (low-resistance pot); 3 sweeps within 24 mV; only ~60 mV at 500 µs, so the pot's low end is close |
| R2_tibia | B3 | 2026-09-27 | 1553 | 1.489 | 64 | 3042 | 21 | > 700 | second batch; 3 sweeps within 29 mV; noise taken parked at 500 µs where the wiper clips at 0 V, so the real p-p is higher |
| R3_coxa | C1 | 2026-09-27 | 1572 | 1.436 | 136 | 3007 | 19 | 570 | second batch; 3 sweeps within 20 mV; noise taken parked at ~3.0 V, not clipped |
| R3_femur | C2 | 2026-09-27 | 1573 | 1.427 | 146 | 3000 | 15 | 740–860 | second batch; 3 sweeps within 19 mV; noise parked at ~2.0 V over 7 readings |
| R3_tibia | C3 | 2026-09-27 | 1524 | 1.476 | 49 | 3000 | 17 | 750–890 | second batch; 3 sweeps within 25 mV; parked at ~2.98 V the spikes reach 3.34 V, above 3.3 V (filtered out on the leg board) |
| L3_coxa | D1 | 2026-09-27 | 1538 | 1.400 | 138 | 2938 | 15 | 530–700 | second batch; 3 sweeps within 34 mV (largest spread so far, at 2500 µs) |
| L3_femur | D2 | 2026-09-27 | 1570 | 1.427 | 143 | 2997 | 16 | 430–920 | second batch; 3 sweeps within 29 mV, the top end identical (2991 mV); at ~2.98 V spikes reach 3.48 V, one 1-s window had a 1.5 V dip |
| L3_tibia | D3 | 2026-09-27 | 1524 | 1.459 | 65 | 2984 | 24 | > 630 | second batch; 4 sweeps within 25 mV; noise parked at 500 µs (~70 mV), clipped at 0 V so the real p-p is higher |
| L2_coxa | E1 | 2026-09-27 | 1541 | 1.422 | 119 | 2962 | 21 | 610–950 | second batch; 3 sweeps within 20 mV; parked at ~2.95 V one spike reached 3.44 V |
| L2_femur | E2 | 2026-09-27 | 1548 | 1.446 | 102 | 2995 | 24 | 670–750 | second batch; 3 sweeps within 25 mV; average steady at 2980 mV across 5 windows |
| L2_tibia | E3 | 2026-09-27 | 1548 | 1.400 | 148 | 2948 | 13 | 530–800 | second batch; best fit so far; 3 sweeps within 34 mV, all of that one reading at 1611 µs, the rest within 20 mV |
| L1_coxa | F1 | 2026-09-27 | 1541 | 1.466 | 74 | 3007 | 24 | > 700 | second batch; 3 sweeps within 25 mV; noise parked at 500 µs, clipped at 0 V. Resumed 8 µs below its position (with R1_coxa's calibration): ignored u 500, u 500 and a ramp to 2500, then followed |
| L1_femur | F2 | 2026-09-27 | 1542 | 1.454 | 89 | 2996 | 23 | 670–770 | second batch; 3 sweeps within 24 mV; average steady at 2980–2981 mV |
| L1_tibia | F3 | 2026-09-27 | 1584 | 1.427 | 156 | 3011 | 17 | 460–560 | second batch; 3 sweeps within 20 mV; quietest of the second batch |

All 18 (2026-09-27): every servo is linear over 500–2500 µs within 24 mV. mid 1522–1646 mV (sd 31), slope 1.366–1.489 mV/µs (sd 0.033), full scale at 2500 µs 2938–3042 mV, so none gets near 3.3 V. One shared calibration would be off by up to 9° between 600 and 2400 µs, so each leg cell stores mid and slope for its three joints.
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

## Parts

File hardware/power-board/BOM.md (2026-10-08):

# Power board BOM

One board: BMS, USB-C charger, power MCU on CAN. Everything from Mouser except the XT60/XT30 (Amass, TME) and the panel button. Prices single-unit, rounded; passives rough. Start each block from TI's reference design (BQ76952EVM for the BMS, BQ25798EVM for the charger).

Parts shared with the side boards (the NTC, BAT54J) use the same MPN. Passives here are 0603 resistors and 0805 capacitors; the side boards use 0402.

## Battery management

| Qty | Part | Value / MPN | Package | ~€ | Notes |
|---|---|---|---|---|---|
| 1 | BMS | BQ7694202PFBR | TQFP-48 | 4.50 | the 02 variant boots with REG1 on at 3.3 V, which starts the MCU; I2C with CRC. Cells on VC1, VC2, VC3, VC10, VC4–VC9 shorted to VC3 |
| 2 | Pack FETs (CHG, DSG) | BSC010N04LSATMA1 | SuperSO8 | 4.00 | high side, back to back; 20 A peak. Any 40 V, ≤ 5 mΩ part would do, these have margin; out of stock at LCSC, where BSC022N04LSATMA1 (2.2 mΩ, same footprint) is $0.52 |
| 1 | Pre-discharge FET + resistor | per the EVM, ~100 Ω 2 W | SOT-23, 2512 | 0.50 | the only inrush limit for the side boards' input caps: size it for them |
| 1 | Coulomb counter shunt | CSS2H-2512R-1L00F (Bourns, 1 mΩ 1 %) | 2512 | 0.50 | Kelvin to SRP/SRN through 100 Ω each, 100 nF across |
| 5 | Cell tap filters | 20 Ω + 100 nF | 0603 | 0.10 | |
| 1 | REG0 pass transistor | BCP56-16 | SOT-223 | 0.20 | REG1 alone gives 45 mA, not enough for CAN |
| 2 | NTC | NCP18XH103F03RB | 0603 / on cable | 0.20 | cell (J-NTC, on TS1) and FETs (TS3); never on TS2. Same part as the side boards |

## Charger (USB-C only)

| Qty | Part | Value / MPN | Package | ~€ | Notes |
|---|---|---|---|---|---|
| 1 | Charger | BQ25798RQMR | VQFN-HR 4×4 | 4.50 | single input: VAC1/VAC2 tied to VBUS, ACDRV1/2 to GND (datasheet 7.3.5.2), no input FETs. PROG 17.4k: 1.5 MHz, 4S |
| 1 | Inductor | XAL5030-102MEC (1 µH) | 5×5 mm | 2.50 | Coilcraft is €2–3 at Mouser and $8.40 at LCSC; the LCSC alternative is in `hardware/BOM_LCSC.csv` |
| 1 | PD sink | CYPD3177-24LQXQ (Infineon) | QFN-24 | 1.90 | asks for 20 V, set by resistors; I2C left open (its address 0x08 is the BMS's) |
| 1 | J-USBC | S6B-XH-A-1 (JST) | TH, horizontal | 0.25 | pigtail to the panel USB-C: VBUS ×2, CC1, CC2, GND ×2 (`interfaces.md`) |
| 1 | Panel USB-C | panel-mount USB-C receptacle, power only, with VBUS, GND, CC1 and CC2 brought out | panel | 3.00 | not a two-wire VBUS/GND socket: the CYPD3177 needs CC |
| 1 | VBUS TVS | SMBJ20A | SMB | 0.30 | |
| 1 | Charger wake | BSS138-7-F | SOT-23 | 0.10 | VBUS present pulls TS2 low |
| – | Caps | per the EVM; VBUS and PMID 10 µF 50 V (20 V PD input) | 0805 / 1206 | 1.00 | |

20 V × 3 A ≈ 60 W, about 2.5 h for the pack. A plain 5 V USB-C source still charges, at about 15 W.

## Power control

| Qty | Part | Value / MPN | Package | ~€ | Notes |
|---|---|---|---|---|---|
| 1 | Power button | momentary, panel | panel | 0.50 | straight to the MCU (PA0), and through the diode to BMS TS2 (wake) |
| 1 | Button diode | BAT54J | SOD-323F | 0.10 | anode on TS2: the USB-C wake FET doesn't read as a press; same part as the leg cells' e-stop diodes |
| 1 | CM5 power cut | 2N7002 + 100k gate pull-down | SOT-23 | 0.10 | pulls the carrier's 5V_EN low; the pull-down keeps the CM5 on through an MCU reset |
| 1 | ESTOP_N series resistor | 100 Ω | 0603 | 0.01 | MCU open-drain pin straight onto ESTOP_N; no buffer, no mushroom button |

## 3.3 V, MCU and CAN

| Qty | Part | Value / MPN | Package | ~€ | Notes |
|---|---|---|---|---|---|
| 1 | 3.3 V buck | TPS62933DRLR + the side boards' inductor and caps | SOT-583 | 1.50 | EN from BMS REG1 |
| 1 | MCU | STM32C092KCT6 | LQFP32 | 2.10 | node 7 |
| 1 | Crystal + load caps | K2B400001210 (KYX, 40 MHz, CL 12 pF) + 2× 18 pF C0G | 2016 | 0.20 | FDCAN needs it; as the side boards |
| 1 | CAN transceiver | TCAN332DR | SOIC-8 | 2.15 | stub off the bus, no termination |
| 1 | CAN ESD | NUP2105LT1G | SOT-23 | 0.15 | |
| 2 | I2C pull-ups | 2.2k | 0603 | 0.02 | BMS and charger share the bus |
| 1 | HALTED pull-down | 100k | 0603 | 0.01 | |
| 1 | LED + resistor | as the side boards | 0805 / 0603 | 0.05 | |
| – | SWD | TC2050 footprint | PCB | – | |

## Protection and connectors

| Qty | Part | Value / MPN | Package | ~€ | Notes |
|---|---|---|---|---|---|
| 1 | Pack TVS | SMBJ18A | SMB | 0.30 | after the pack FETs; same as the side boards (TPS56A37 is 32 V abs max) |
| 1 | Main fuse | Littelfuse ATO 30 A + FHAC inline holder | cable | 3.00 | in the pack lead |
| 1 | Bulk cap | 100 µF 35 V, the side boards' part | SMD | 0.60 | |
| 1 | Pack | XT60PW-M (Amass) | TH | 0.70 | TME; the pack keeps the hooded half |
| 1 | Balance | B5B-XH-A (JST) | TH | 0.20 | one 5-pin plug with all taps, as on drone packs: GND, C1, C2, C3, C4 |
| 1 | Cell NTC | B2B-PH-K-S (JST) | TH | 0.10 | DIY pack only; drone packs have none |
| 1 | Power button | B2B-PH-K-S (JST) | TH | 0.10 | |
| 3 | Sides, carrier | XT30PW-M (Amass) | TH | 1.50 | VBAT to both side boards and the carrier; TME |
| 1 | J-SYSCTL | S10B-XH-A-1 (JST) | TH, horizontal | 0.35 | CAN stub, ESTOP_N and the CM5 control lines to the carrier in one cable (`interfaces.md`) |

About **€35** in parts, plus the PCB (4 layers, 2 oz).

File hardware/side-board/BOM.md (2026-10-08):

# Side board BOM

Per board = 3 leg cells + shared parts. Small resistors and capacitors are 0402; test points are 1 mm pads. Two boards per robot. Prices are single-unit (DigiKey/Mouser, 2026-09), rounded; passives are rough.

## Per leg cell (×3 per board)

| Qty | Part | Value / MPN | Package | ~€ | Notes |
|---|---|---|---|---|---|
| 1 | MCU | STM32C092KCT6 | LQFP32 | 2.10 | |
| 1 | Crystal | KYX K2B400001210: 40 MHz, CL 12 pF, ±10 ppm, ESR ≤ 40 Ω | 2016 | 0.15 | at worst-case ESR its gm_crit (~1.7–2 mA/V) is over the C0's 1.5 mA/V start-up limit: check start-up on the first boards |
| 2 | Crystal load caps | 18 pF C0G, 2 × (12 − 3) pF | 0805 | 0.02 | |
| 2 | MCU decoupling | 100 nF + 4.7 µF on VDD/VDDA | 0402 / 0805 | 0.05 | |
| 1 | NRST cap | 100 nF | 0402 | 0.01 | |
| 1 | CAN transceiver | TCAN332DR | SOIC-8 | 2.15 | 3.3 V-only, which is what the board has (TJA1051T/3 needs 5 V) |
| 1 | Servo buck | TPS56A37RPAR | VQFN-HR 3×3 | 2.70 | 4.5–28 V in, 10 A, 32 V abs max |
| 1 | Buck inductor | SRP7050WA-4R7M (Bourns): 4.7 µH, Isat 13.3 A, Irms 10.5 A, 20.5 mΩ max | 7.9×7.3 mm | 1.20 | WEBENCH in `docs/`: 8.8 A peak at 8 A, 520 kHz. Not the Sunlord MWSA0804S: only ~20 % saturation margin over a three-servo stall |
| 2 | Buck input caps | 15 µF + 1 µF, 35 V X7R | 1206 / 0805 | 0.25 | after the cell fuse |
| 2 | Buck output caps | 15 µF 16 V X7R | 1206 | 0.25 | plus 100 pF feed-forward across the top feedback resistor |
| 1 | Bootstrap cap | 100 nF | 0402 | 0.01 | |
| 1 | Soft-start cap | 22 nF | 0402 | 0.01 | slows the inrush when a leg wakes |
| 2 | Buck feedback | 90.9k / 10k 1 % (6.0 V from 0.6 V) | 0402 | 0.02 | |
| 1 | EN pull-down | 100k | 0402 | 0.01 | R217: buck off while the MCU is in reset |
| 1 | E-stop diode | BAT54J | SOD-323F | 0.10 | anode BUCK_EN, cathode ESTOP_N: the hardware e-stop holds the servo buck off |
| 1 | BUCK_EN series | 1k | 0402 | 0.01 | between PB0 and BUCK_EN, so the diode wins over the MCU pin |
| 1 | PG pull-up | 100k | 0402 | 0.01 | R218 |
| 1 | Current amp | INA181A1IDBVR (×20) | SOT-23-6 | 0.40 | + 100 nF |
| 1 | Shunt | 10 mΩ 1 %, ≥ 1 W | 2512 | 0.30 | 7.5 A stall → 0.56 W |
| 3 | Pot series R | 10k | 0402 | 0.01 | wiper → 10k → ADC |
| 3 | Pot divider bottom | 10k, DNP | 0402 | – | no divider needed, see docs/servos.md |
| 3 | Pot RC | 0 Ω link, 100 nF at the ADC | 0402 | 0.02 | with the 10k series R: 160 Hz |
| 3 | PWM series | 220 Ω | 0402 | 0.01 | |
| 3 | PWM pull-down | 10k | 0402 | 0.01 | servo sees no pulses while the MCU boots |
| 3 | Servo connector | 2.54 mm pin header 1×04 (or one 3×4 header per leg) | TH, vertical | 0.05 | ~3 A/pin; GND, V+, PWM, POT: the servo's own plug on pins 1–3, the pot wire on a 1-pin Dupont on pin 4; glued |
| 1 | NTC | NCP18XH103F03RB | 0603 | 0.10 | next to the inductor |
| 1 | NTC pull-up | 10k 1 % | 0402 | 0.01 | |
| 2 | VBAT divider | 100k / 15k 1 % + 100 nF | 0402 | 0.03 | PA5 |
| 2 | 6V0 divider | 15k / 10k 1 % + 100 nF | 0402 | 0.03 | PA6 |
| 2 | LED + resistor | any 0805 LED, 1k | 0805 / 0402 | 0.05 | PA15 (green), 6V0 present (red) |
| 1 | ToF connector | 2.54 mm pin header 1×04 | TH, vertical | 0.05 | 3V3, GND, SDA, SCL |
| 2 | I2C pull-ups | 2.2k, DNP by default | 0402 | – | most VL53L1X breakouts have their own |
| 1 | Cell fuse | 5 A fast, Littelfuse 0466005.NR | 1206 | 0.30 | in the buck's VIN: a shorted leg can't take the side down; 32 V, 11 mΩ |
| – | Leg ID | 3 solder jumpers | PCB | – | |
| – | SWD | 1 mm pads: SWDIO, SWCLK (PA14, net BOOT0), NRST | PCB | – | for PCBite probes; 3V3 and GND from the shared J104 |

About **€10 per leg cell**, ICs included.

## Shared on each board

| Qty | Part | Value / MPN | Package | ~€ | Notes |
|---|---|---|---|---|---|
| 1 | Power in | XT30PW-M (Amass) | TH | 0.50 | not a Mouser part: LCSC/AliExpress |
| 1 | TVS | SMBJ18A | SMB | 0.30 | clamps ~29 V, under the buck's 32 V abs max |
| 1 | Bulk cap | 100 µF 35 V low-ESR (polymer or electrolytic) | SMD | 0.60 | at the XT30, before the three cells |
| 1 | 3.3 V buck | TPS62933DRLR | SOT-583 | 1.00 | 3.8–30 V in, 3 A; stays on in Sentinel |
| 1 | 3.3 V inductor | SRP4020TA-4R7M (Bourns): 4.7 µH, Isat 3.5 A, 105 mΩ | 4.4×4.2 mm | 1.00 | ~0.3 A load; same part as the power board. LCSC equivalents for a tenth of the price in `hardware/BOM_LCSC.csv` |
| 5 | 3.3 V caps | 10 µF 35 V + 100 nF in, 47 µF out, 100 nF boot, 33 nF SS | 0805/1206 | 0.30 | |
| 2 | 3.3 V feedback | 30.9k / 10k 1 % | 0402 | 0.02 | |
| 2 | CAN connectors | JST XH 4-pin S4B-XH-A-1 (in, out) | TH, horizontal | 0.40 | CANH, CANL, GND, ESTOP_N |
| 1 | CAN ESD | NUP2105LT1G | SOT-23 | 0.30 | both connectors are on the same bus |
| 1 | CAN termination | 120 Ω + solder jumper | 0402 | 0.01 | close the jumper only at the outer end of the bus |
| 1 | SWD power | 1×02 pin header, 2.54 mm (J104): 3V3, GND | TH | 0.05 | shared by the three cells, for jumper wires |
| 4 | Mounting holes | M3 | PCB | – | |

About **€7 shared**, so **~€37 per side board** in parts, **~€74 for both**, plus PCBs and stencil.

## Cheaper options

- **TCAN332DR** is the biggest single item after the MCU and buck. There's no cheaper drop-in 3.3 V-only transceiver on the same footprint that I'd trust more, so keep it; quantity breaks at 10+ help (six legs + carrier + power board).
- **TPS56A37RPAR** is also on LCSC from about €1.20 if you split the order.
- Passives and connectors: LCSC is usually half the Mouser price; ICs from Mouser in one order, as planned.

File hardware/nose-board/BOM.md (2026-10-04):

# Nose board BOM

Small 2-layer board in the nose cone: front ToF, compass, and the Pi camera screwed on next to the ToF. Design notes in `docs/spec.md` (Nose board), connector in `docs/interfaces.md` (J-NOSE). Prices single-unit, rounded.

| Qty | Part | Value / MPN | Package | ~€ | Notes |
|---|---|---|---|---|---|
| 1 | Front ToF | VL53L8CX | optical LGA16, 6.4 × 3.0 mm | 7.00 | keep the lens film on while soldering; thermal pad to GND with vias |
| 1 | 1.8 V LDO | TLV75518PDBVR (or AP2112K-1.8) | SOT-23-5 | 0.40 | CORE_1V8 + IOVDD, 50–80 mA while ranging |
| 1 | I2C level shifter | PCA9306 | VSSOP-8 | 0.60 | 3.3 V carrier ↔ 1.8 V sensor |
| 2 | Level shift FETs | BSS138 | SOT-23 | 0.20 | LPn (in), INT (out); gate on 1.8 V, 10k to 3.3 V on the carrier side |
| 1 | PCA9306 EN | 200k | 0603 | – | VREF2 and EN to 3.3 V (TI app circuit) |
| 2 | I2C pull-ups, sensor side | 2.2k | 0603 | – | to 1.8 V |
| 2 | I2C pull-ups, carrier side | 4.7k | 0603 | – | to 3.3 V, DNP if the carrier has them |
| 5 | Straps | 47k | 0603 | – | SPI_I2C_N, NCS to GND; INT, LPn, SYNC to 1.8 V |
| 6 | ToF decoupling | 4.7 µF + 100 nF each on AVDD, IOVDD, CORE_1V8 | 0805/0603 | 0.10 | at the pins |
| 2 | LDO caps | 1 µF in, 1 µF out | 0603 | 0.02 | |
| 1 | Compass | MMC5983MA | LGA-16 3×3 | 3.00 | 3.3 V, I2C 0x30; SPI_CS to 3.3 V, SDO open; keep copper and screws around it non-magnetic |
| 3 | Compass passives | 1 µF VDD, 10 µF CAP, 100k INT pull-down | 0603/0805 | 0.05 | INT is hi-Z until enabled |
| 1 | Status LED + resistor | any 0603 | 0603 | 0.05 | |
| 1 | Connector | SM08B-GHS-TB (JST-GH 8) | SMD | 0.60 | J-NOSE |
| 4 | Camera mount | M2 holes, Pi camera module pattern | PCB | – | camera axis parallel to the ToF |

About **€12** in parts, plus the PCB.

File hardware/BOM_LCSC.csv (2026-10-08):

LCSC Part Number | Manufacture Part Number | Quantity | Manufacturer | Description | Boards | LCSC price USD (1 pc) | LCSC stock | Mouser BOM price EUR | Buy at | Notes
C22392669 | TPS56A37RPAR | 7 | Texas Instruments | 10 A buck, 6 V servo rail / 5 V CM5 rail | side ×6, carrier ×1 | 2.07 | 26979 | 2.7 | LCSC
C73651 | TCAN332DR | 7 | Texas Instruments | 3.3 V CAN transceiver | side ×6, power ×1 | 1.8 | 435 | 2.15 | LCSC | TME: special order, 0 in stock
C2876593 | BQ25798RQMR | 1 | Texas Instruments | USB-C buck-boost charger | power | 2.93 | 5165 | 4.5 | LCSC
C3682863 | BQ7694202PFBR | 1 | Texas Instruments | BMS, the 02 (I2C, REG1 on) variant | power | 3.26 | 34 | 4.5 | LCSC | low stock; not the 04 (SPI) variant
C404329 | MMC5983MA | 1 | MEMSIC | compass | nose | 2.26 | 15622 | 3.0 | LCSC
C3200405 | TPS62933DRLR | 3 | Texas Instruments | 3.3 V buck | side ×2, power ×1 | 0.6 | 33117 | 1.0 | LCSC
C49206925 | BSC022N04LSATMA1 | 2 | Infineon | 40 V 2.2 mΩ pack FET (CHG, DSG) | power | 0.52 | 693 | 2.0 | LCSC | alternative to the schematic's BSC010N04LSATMA1 (out of stock at LCSC), same SuperSO8 footprint; change the schematic if used
C19947706 | SRP7050WA-4R7M | 6 | Bourns | 4.7 µH 13.3 A servo-buck inductor | side ×6 | 1.32 | 211 | 1.2 | either | +1 if the carrier's 5 V buck uses the same inductor
C3040385 |  | 3 | Changjiang Microelectronics | 3.3 V buck inductor (4.4×4.2 mm, 4.7 µH, 105 mΩ, Isat 3 A) | side ×2, power ×1 | 0.18 | 2078 | 1.0 | LCSC | drop-in for the Bourns SRP4020TA-4R7M (C2041623, $1.19); MWSA0402S-4R7MT C408337 ($0.15) is another
C5298161 |  | 1 | Changjiang Microelectronics | charger inductor (1 µH, 5.4×5.2 mm, Isat 10 A, 14 mΩ) | power | 0.28 | 247 | 2.5 | LCSC | alternative to the Coilcraft XAL5030-102MEC ($8.40 at LCSC); check the footprint
C30170175 | XT30PW-M | 6 | Changzhou Amass | XT30 PCB plug, right angle | side ×2, power ×3, carrier ×1 | 0.37 | 1557 | 0.5 | LCSC | saves the TME order for these
C14486 | NUP2105LT1G | 3 | onsemi | CAN ESD | side ×2, power ×1 | 0.08 | 272850 | 0.3 | LCSC | + carrier
C10212 | SMBJ18A | 3 | various | 18 V TVS on VBAT | side ×2, power ×1 | 0.08 | 2029 | 0.3 | LCSC
C4175647 | CSS2H-2512R-1L00F | 1 | Bourns | 1 mΩ coulomb-counter shunt | power | 0.56 | 1511 | 0.5 | either
C2952489 | CYPD3177-24LQXQT | 1 | Infineon | USB-PD sink, asks for 20 V | power | 1.7 | 1164 | 1.9 | either | T = tape and reel, same part
C45338514 | STM32C092KCT6 | 8 | STMicroelectronics | MCU | side ×6, power ×1, carrier IO ×1 | 2.81 | 25 | 2.1 | Mouser | cheaper at Mouser, and LCSC stock is only 25
C7386355 | VL53L8CXV0GC/1 | 1 | STMicroelectronics | 8×8 front ToF | nose | 10.17 | 2426 | 7.0 | Mouser
C2058943 | INA181A1IDBVR | 6 | Texas Instruments | leg current amp | side ×6 | 0.49 | 1950 | 0.4 | Mouser | LCSC clones (LX C52097916, XBLW C45351496) are $0.15–0.20; keep TI for the offset
C33196 | PCA9306DCUR | 1 | Texas Instruments | I2C level shifter | nose | 0.72 | 11715 | 0.6 | Mouser
 | XT60PW-M | 1 | Changzhou Amass | XT60 PCB plug (pack) | power |  |  | 0.7 | TME | LCSC C98732 is pre-order, minimum 16

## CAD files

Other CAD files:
software/ros2_ws/src/vector_description/meshes/TibiaAssemblyv2_2__TOFSensorFrontplate.stl
software/ros2_ws/src/vector_description/meshes/TibiaAssemblyv2_2_2__TOFSensorFrontplate.stl
software/ros2_ws/src/vector_description/meshes/TibiaAssemblyv2_2__Body18.stl
software/ros2_ws/src/vector_description/meshes/TibiaAssemblyv2_2_2__Reinforcement.stl
software/ros2_ws/src/vector_description/meshes/TibiaAssemblyv2_2_2__RubberPad.stl
software/ros2_ws/src/vector_description/meshes/TibiaAssemblyv2_2_1__TOFSensorFrontplate.stl
software/ros2_ws/src/vector_description/meshes/TibiaAssemblyv2_2__RubberPad.stl
software/ros2_ws/src/vector_description/meshes/TibiaAssemblyv2_2_2__TibiaBasePlate.stl
software/ros2_ws/src/vector_description/meshes/TibiaAssemblyv2_2_0__TibiaBasePlate.stl
software/ros2_ws/src/vector_description/meshes/TibiaAssemblyv2_2_1__TibiaSide2.stl
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

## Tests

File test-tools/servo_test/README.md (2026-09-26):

# servo_test

Arduino Uno sketch to put one MG996R at a set angle over serial and read the modded pot wiper, for measuring the wiper voltage range and noise.

## Wiring

| Servo | Goes to |
|---|---|
| red (V+) | bench supply 6.0 V, current limit ~1 A (not the Uno 5V pin, the servo pulls too much) |
| brown (GND) | supply GND and Uno GND |
| orange (signal) | D9 |
| blue (wiper) | A0 directly |

The MG996R's pot runs off its internal regulator, so the wiper stays around 1–2.5 V even at 6 V supply and can go straight to A0. The sketch reads it as is (`k 100`); use `k 200` if you add a 100k/100k divider.

On the first `a`/`u` after a stop the sketch starts the pulses at the position read from the wiper plus 30 µs, because these servos ignore commands if the first pulse is even slightly below where they sit. That needs the right calibration: `c` loads the new servo's own numbers, `m <mid> <slope×1000>` loads them from `docs/servos.md` (e.g. `m 1593 1374`). The default is R1_coxa's. If a servo ignores commands, send a pulse above where it sits (`u 2600`) and it wakes up.

## Use

Serial monitor at 115200, line ending "Newline".

```
a 90              go to 90 deg, prints pulse, ADC and wiper mV
u 1500            go to a pulse width directly
s 0 180 10 500    sweep 0-180 in 10 deg steps, 500 ms settle, prints CSV
c R1_femur        calibrate that servo (label A2): sweep 500-2500 us, fit a line, print a row for docs/servos.md
m 1593 1374       load a calibration (mid mV, slope x1000) from docs/servos.md
n                 wiper min/avg/max over 1 s (noise; push on the horn to load it)
d                 dump 256 raw wiper samples at full ADC speed (~9.6 kHz), for looking at the noise
o                 stop pulses, servo goes limp
w 500             move speed in us/s (500 = ~90 deg/s, default), w 0 jumps straight there
p                 measure the pulses on D9 (should be ~50 Hz, width as commanded)
f                 check A0 is really on the wiper (a floating A0 reads garbage)
v 4950            set the real 5V pin voltage (measure it) for accurate mV
k 100             divider ratio x100 (100 = wiper straight to A0, the default; 200 for 100k/100k)
```

Run `f` first: if it says FLOATING, the wiper reading means nothing (check the blue wire lands on A0). In the Serial Monitor set the line ending to Newline, or no command runs.

Pulses map 0-180 deg to 500-2500 us (`US_MIN`/`US_MAX` at the top of the sketch), which is 180 deg of real rotation on the first modded servo: it turns 90 deg per 1000 us and stays linear from 400 to 2600 us.

What to record in `docs/power-budget.md`: wiper mV at 0, 90 and 180 deg, the pot's top-end voltage, and the noise spread while holding still and while loaded.

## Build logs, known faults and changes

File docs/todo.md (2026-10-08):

# To do

## Software

- Set materials in Fusion so the CAD masses mean something (the export is scaled by volume), then rerun `tools/cad_urdf.py` with the real total.
- Check the VL53L8CX zone orientation (`flip_x`, `flip_y` in `tof_front`) with a hand in one corner.
- Calibrate the OV5647 (checkerboard): the ground projection and the ToF fusion use datasheet angles.
- LTE (A7670E on UART4): APN on the modem, PPP over the UART, then a drive over LTE with the operator page.
- On the carrier: set `imu_axes`, `mag_axes` from the board layouts and calibrate the compass in the robot; set `lidar_yaw` and `lidar_clockwise` once the LDS01RR is mounted (an object on one side shows the direction).
- IO MCU bring-up: check the ROM bootloader jump and `io_flash.py` on the real chip, the LDS01RR motor loop on the real motor and the buzzer frequency.

## Hardware

- Schematics for the 10-pin J-SYSCTL (power board J101 + J102, carrier J502) and the J-USBC pigtail header (power board J301), per `interfaces.md`.
- Carrier: layout (CM5 placement and the 90/100 Ω pairs from the CM5 IO board).
- XT60 / XT30 aren't on Mouser: order from TME.

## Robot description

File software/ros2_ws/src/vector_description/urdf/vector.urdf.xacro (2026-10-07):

<?xml version="1.0"?>
<robot name="vector" xmlns:xacro="http://www.ros.org/wiki/xacro">
  <xacro:arg name="hardware" default="mock"/>
  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
  <xacro:arg name="controllers" default=""/>
  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
  <xacro:arg name="can_interface" default="can0"/>

  <xacro:property name="g" value="${xacro.load_yaml('$(find vector_description)/config/legs.yaml')}"/>
  <xacro:property name="lc" value="${g['coxa']}"/>
  <xacro:property name="lf" value="${g['femur']}"/>
  <xacro:property name="lt" value="${g['tibia']}"/>
  <xacro:property name="lim" value="${g['limits']}"/>
  <xacro:property name="mass" value="${g['mass']}"/>
  <xacro:property name="gazebo" value="${'$(arg hardware)' == 'gazebo'}"/>

  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
  <xacro:property name="sr" value="${g['stand']['reach'] - lc}"/>
  <xacro:property name="sz" value="${-g['stand']['height']}"/>
  <xacro:property name="sd" value="${hypot(sr, sz)}"/>
  <xacro:property name="stand_femur" value="${atan2(sz, sr) + acos((lf*lf + sd*sd - lt*lt) / (2*lf*sd))}"/>
  <xacro:property name="stand_tibia" value="${acos((lf*lf + lt*lt - sd*sd) / (2*lf*lt)) - pi}"/>

  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

  <xacro:property name="bl" value="${g['body']['length']}"/>
  <xacro:property name="bw" value="${g['body']['width']}"/>
  <xacro:property name="bt" value="${g['body']['thickness']}"/>
  <xacro:property name="bm" value="${mass['body']}"/>

  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
  <link name="base_link">
    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
  </link>
  <link name="body_mass">
    <inertial>
      <mass value="${bm}"/>
      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
    </inertial>
  </link>
  <joint name="body_mass_joint" type="fixed">
    <parent link="base_link"/>
    <child link="body_mass"/>
  </joint>

  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
  <link name="nose_tof"/>
  <joint name="nose_tof_joint" type="fixed">
    <parent link="base_link"/>
    <child link="nose_tof"/>
    <origin xyz="0.12 0 0.02"/>
  </joint>

  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
  <link name="lidar"/>
  <joint name="lidar_joint" type="fixed">
    <parent link="base_link"/>
    <child link="lidar"/>
    <origin xyz="0 0 0.055"/>
  </joint>

  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
  <link name="gnss"/>
  <joint name="gnss_joint" type="fixed">
    <parent link="base_link"/>
    <child link="gnss"/>
    <origin xyz="-0.05 0 0.08"/>
  </joint>

  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
  <xacro:macro name="segment" params="name length radius m">
    <link name="${name}">
      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
      <inertial>
        <origin xyz="${length/2} 0 0"/>
        <mass value="${m}"/>
        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
      </inertial>
    </link>
  </xacro:macro>

  <xacro:macro name="leg" params="name">
    <xacro:property name="m" value="${g['mounts'][name]}"/>

    <xacro:segment name="${name}_coxa_link" length="${lc}" radius="0.012" m="${mass['coxa_link']}"/>
    <xacro:segment name="${name}_femur_link" length="${lf}" radius="0.010" m="${mass['femur_link']}"/>
    <xacro:segment name="${name}_tibia_link" length="${lt}" radius="0.008" m="${mass['tibia_link']}"/>
    <link name="${name}_foot">
      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
      <inertial>
        <mass value="0.005"/>
        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
      </inertial>
    </link>
    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

    <joint name="${name}_coxa" type="revolute">
      <parent link="base_link"/>
      <child link="${name}_coxa_link"/>
      <origin xyz="${m['x']} ${m['y']} 0" rpy="0 0 ${m['yaw']}"/>
      <axis xyz="0 0 1"/>
      <limit lower="${lim['coxa'][0]}" upper="${lim['coxa'][1]}" effort="${lim['effort']}" velocity="${lim['velocity']}"/>
    </joint>
    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
    <joint name="${name}_femur" type="revolute">
      <parent link="${name}_coxa_link"/>
      <child link="${name}_femur_link"/>
      <origin xyz="${lc} 0 0"/>
      <axis xyz="0 -1 0"/>
      <limit lower="${lim['femur'][0]}" upper="${lim['femur'][1]}" effort="${lim['effort']}" velocity="${lim['velocity']}"/>
    </joint>
    <joint name="${name}_tibia" type="revolute">
      <parent link="${name}_femur_link"/>
      <child link="${name}_tibia_link"/>
      <origin xyz="${lf} 0 0"/>
      <axis xyz="0 -1 0"/>
      <limit lower="${lim['tibia'][0]}" upper="${lim['tibia'][1]}" effort="${lim['effort']}" velocity="${lim['velocity']}"/>
    </joint>
    <joint name="${name}_foot_joint" type="fixed">
      <parent link="${name}_tibia_link"/>
      <child link="${name}_foot"/>
      <origin xyz="${lt} 0 0"/>
    </joint>

    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
    <link name="${name}_tof"/>
    <joint name="${name}_tof_joint" type="fixed">
      <parent link="${name}_tibia_link"/>
      <child link="${name}_tof"/>
      <origin xyz="${g['tof']['x']} 0 ${g['tof']['z']}" rpy="0 ${g['tof']['pitch']} 0"/>
    </joint>
    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
    <xacro:if value="${gazebo}">
      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
    </xacro:if>
  </xacro:macro>

  <xacro:leg name="L1"/>
  <xacro:leg name="L2"/>
  <xacro:leg name="L3"/>
  <xacro:leg name="R1"/>
  <xacro:leg name="R2"/>
  <xacro:leg name="R3"/>

  <xacro:macro name="joint_if" params="name initial">
    <joint name="${name}">
      <command_interface name="position"/>
      <state_interface name="position"><param name="initial_value">${initial}</param></state_interface>
      <state_interface name="velocity"/>
      <state_interface name="effort"/>
    </joint>
  </xacro:macro>

  <xacro:macro name="leg_if" params="name">
    <xacro:joint_if name="${name}_coxa" initial="0.0"/>
    <xacro:joint_if name="${name}_femur" initial="${stand_femur}"/>
    <xacro:joint_if name="${name}_tibia" initial="${stand_tibia}"/>
  </xacro:macro>

  <ros2_control name="vector" type="system">
    <hardware>
      <xacro:if value="${'$(arg hardware)' == 'mock'}">
        <plugin>mock_components/GenericSystem</plugin>
      </xacro:if>
      <xacro:if value="${gazebo}">
        <plugin>gz_ros2_control/GazeboSimSystem</plugin>
      </xacro:if>
      <xacro:if value="${'$(arg hardware)' == 'can'}">
        <plugin>vector_hw/VectorSystem</plugin>
        <param name="can_interface">$(arg can_interface)</param>
        <param name="timeout_ms">100</param>
      </xacro:if>
    </hardware>
    <xacro:leg_if name="L1"/>
    <xacro:leg_if name="L2"/>
    <xacro:leg_if name="L3"/>
    <xacro:leg_if name="R1"/>
    <xacro:leg_if name="R2"/>
    <xacro:leg_if name="R3"/>
    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
    <xacro:unless value="${gazebo}">
      <gpio name="legs">
        <command_interface name="enable"/>
        <command_interface name="estop"/>
        <state_interface name="enable"><param name="initial_value">1.0</param></state_interface>
      </gpio>
    </xacro:unless>
  </ros2_control>

  <xacro:if value="${gazebo}">
    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
  </xacro:if>
</robot>

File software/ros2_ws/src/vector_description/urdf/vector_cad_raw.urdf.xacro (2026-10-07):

<?xml version='1.0' encoding='utf-8'?>
<robot xmlns:xacro="http://www.ros.org/wiki/xacro" name="V.E.C.T.O.R.">
   <xacro:include filename="$(find vector_description)/urdf/vector_cad_materials.xacro" />
   <link name="dummy_link" />
   <joint name="dummy_link_joint" type="fixed">
      <parent link="dummy_link" />
      <child link="base_linkv8_1" />
   </joint>
   <link name="base_linkv8_1">
      <inertial>
         <origin xyz="-0.0018772313854202062 -6.831789961107053e-06 0.0014778649263716926" rpy="0.0 0.0 3.141592653589793" />
         <mass value="1.2686581992949608" />
         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
      </inertial>
      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
   </link>
   <link name="TopPlate_1">
      <inertial>
         <origin xyz="-0.00010921397547406064 1.1301399740667222e-05 0.021399999443451643" rpy="0.0 0.0 3.141592653589793" />
         <mass value="0.2513987840352954" />
         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
      </inertial>
      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
   </link>
   <link name="ReinforcementPlate_1">
      <inertial>
         <origin xyz="-0.00020660958419582487 0.0006267751670009789 0.022000000000000002" rpy="0.0 0.0 3.141592653589793" />
         <mass value="0.08547532263943959" />
         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
      </inertial>
      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
   </link>
   <link name="CoxaServoAssembly_1">
      <inertial>
         <origin xyz="0.0893150541355548 -0.03263535407427847 -0.004978940218193806" rpy="-1.5707963267948966 0.7853981633974585 -1.5707963267948966" />
         <mass value="0.2407919102798682" />
         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
      </inertial>
   </link>
   <link name="CoxaServoAssembly_1_0">
      <inertial>
         <origin xyz="0.08931505413555481 -0.03263535407427847 -0.004978940218193913" rpy="-1.5707963267948966 0.0 -1.5707963267948966" />
         <mass value="0.2407919102798682" />
         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
      </inertial>
   </link>
   <link name="CoxaServoAssembly_1_1">
      <inertial>
         <origin xyz="0.08931505413555481 -0.03263535407427835 -0.004978940218193806" rpy="1.5707963267948966 -0.7853981633974496 1.5707963267948966" />
         <mass value="0.2407919102798682" />
         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
      </inertial>
   </link>
   <link name="CoxaServoAssembly_1_3">
      <inertial>
         <origin xyz="0.08931505413555481 -0.03263535407427841 -0.004978940218193948" rpy="1.5707963267948966 0.0 1.5707963267948966" />
         <mass value="0.2407919102798682" />
         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
      </inertial>
   </link>
   <link name="CoxaServoAssembly_1_4">
      <inertial>
         <origin xyz="0.08931505413555484 -0.032635354074278436 -0.0049789402181938235" rpy="1.5707963267948966 0.7853981633974532 1.5707963267948966" />
         <mass value="0.2407919102798682" />
         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
      </inertial>
   </link>
   <link name="ServoMountv17_1">
      <inertial>
         <origin xyz="0.009496810901016462 0.008593417004839416 -0.007069952519590395" rpy="-1.5707963267948966 0.7853981633974318 0.0" />
         <mass value="0.016268702078190932" />
         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
      </inertial>
      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
   </link>
   <link name="ServoMG996Rv1_1">
      <inertial>
         <origin xyz="7.847128724591812e-10 0.018862565434485133 0.00019573987745458155" rpy="-1.5707963267948966 0.7853981633974323 0.0" />
         <mass value="0.2245232082016773" />
         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
      </inertial>
      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
   </link>
   <link name="ServoMountv17_1_0">
      <inertial>
         <origin xyz="0.009496810901016452 0.008593417004839416 -0.0070699525195903855" rpy="-1.5707963267948966 0.0 0.0" />
         <mass value="0.016268702078190932" />
         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
      </inertial>
      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
   </link>
   <link name="ServoMG996Rv1_1_0">
      <inertial>
         <origin xyz="7.847128391524905e-10 0.018862565434485133 0.00019573987745458155" rpy="-1.5707963267948966 0.0 0.0" />
         <mass value="0.2245232082016773" />
         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
      </inertial>
      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
   </link>
   <link name="ServoMountv17_1_1">
      <inertial>
         <origin xyz="0.009496810901016466 0.008593417004839416 -0.0070699525195903595" rpy="1.5707963267948966 -0.7853981633974217 3.141592653589793" />
         <mass value="0.016268702078190932" />
         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
      </inertial>
      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
   </link>
   <link name="ServoMG996Rv1_1_1">
      <inertial>
         <origin xyz="7.847128458138286e-10 0.01886256543448514 0.00019573987745458155" rpy="1.5707963267948966 -0.7853981633974225 -3.141592653589793" />
         <mass value="0.2245232082016773" />
         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
      </inertial>
      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
   </link>
   <link name="ServoMountv17_1_3">
      <inertial>
         <origin xyz="0.009496810901016452 0.008593417004839416 -0.0070699525195903595" rpy="1.5707963267948966 0.0 3.141592653589793" />
         <mass value="0.016268702078190932" />
         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
      </inertial>
      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
   </link>
   <link name="ServoMG996Rv1_1_3">
      <inertial>
         <origin xyz="7.847128347115984e-10 0.01886256543448514 0.000195739877454546" rpy="1.5707963267948966 0.0 3.141592653589793" />
         <mass value="0.2245232082016773" />
         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
      </inertial>
      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
   </link>
   <link name="ServoMountv17_1_4">
      <inertial>
         <origin xyz="0.009496810901016471 0.008593417004839425 -0.007069952519590377" rpy="1.5707963267948966 0.7853981633974825 3.141592653589793" />
         <mass value="0.016268702078190932" />
         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
      </inertial>
      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
   </link>
   <link name="ServoMG996Rv1_1_4">
      <inertial>
         <origin xyz="7.847128280502602e-10 0.018862565434485168 0.0001957398774545638" rpy="1.5707963267948966 0.7853981633974829 3.141592653589793" />
         <mass value="0.2245232082016773" />
         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
      </inertial>
      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
   </link>
   <link name="ServoMountv17_1_2">
      <inertial>
         <origin xyz="0.009496810901016452 0.008593417004839399 -0.007069952519590377" rpy="-1.5707963267948966 -0.7853981633974779 0.0" />
         <mass value="0.016268702078190932" />
         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

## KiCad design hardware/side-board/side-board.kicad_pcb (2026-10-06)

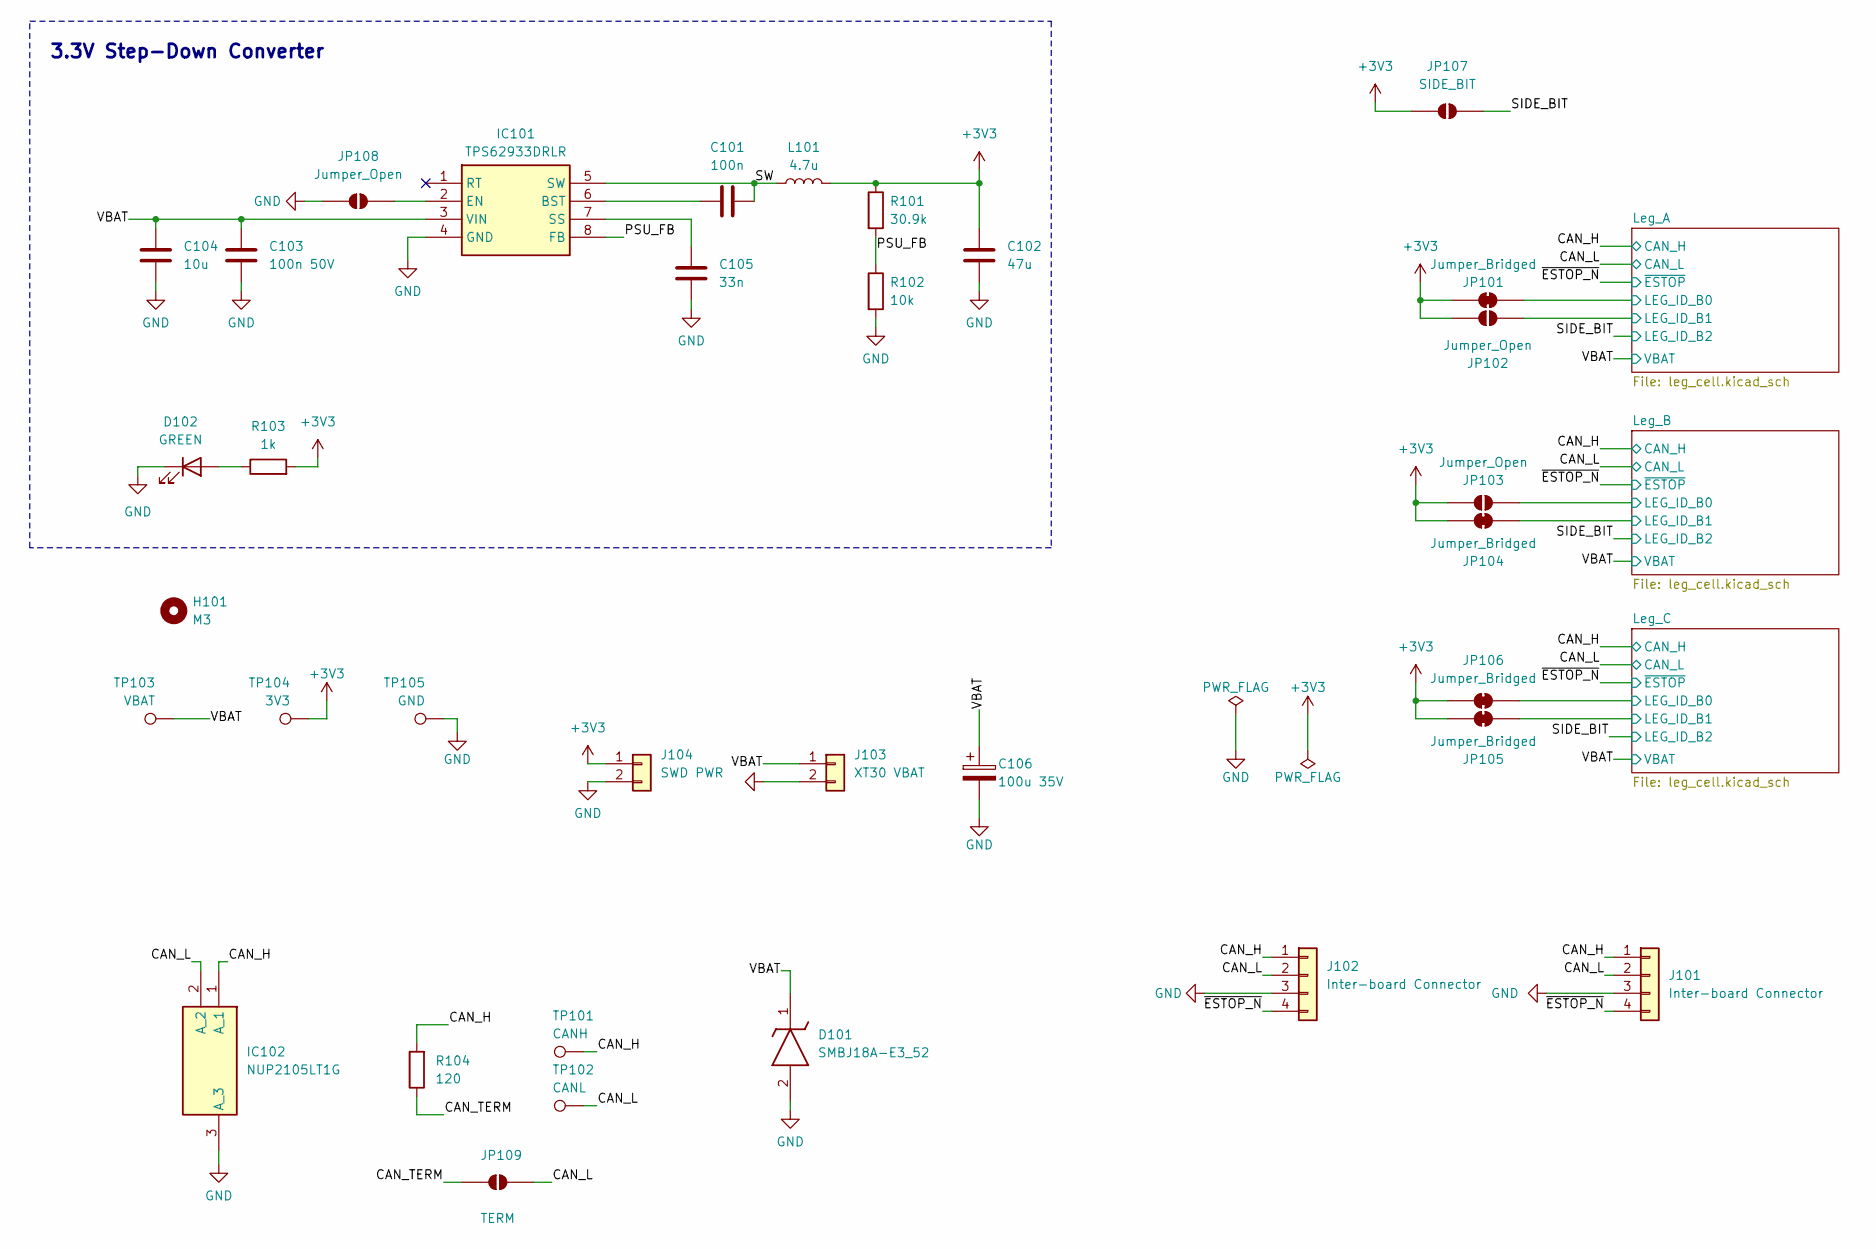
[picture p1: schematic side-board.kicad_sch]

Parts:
C101: 100n; C_0402_1005Metric
C102: 47u; C_0805_2012Metric
C103: 100n 50V; C_0402_1005Metric
C104: 10u; C_0603_1608Metric
C105: 33n; C_0402_1005Metric
C106: 100u 35V; CP_Elec_8x10.5
D101: SMBJ18A-E3_52; DIOM5436X244N; Mouser Part Number 625-SMBJ18A-E3
D102: GREEN; LED_0805_2012Metric
H101: M3; MountingHole_3.2mm_M3_DIN965_Pad_TopBottom
IC101: TPS62933DRLR; SOTFL50P160X60-8N; Mouser Part Number 595-TPS62933DRLR
IC102: NUP2105LT1G; SOT96P237X111-3N; Mouser Part Number 863-NUP2105LT1G
J101: Inter-board Connector; PinHeader_1x04_P2.54mm_Vertical_Tile
J102: Inter-board Connector; JST_XH_B4B-XH-A_1x04_P2.50mm_Vertical
J103: XT30 VBAT; AMASS_XT30U-M_1x02_P5.0mm_Vertical
J104: SWD PWR; PinHeader_1x02_P2.54mm_Vertical
JP101, JP104, JP105, JP106: Jumper_Bridged; SolderJumper-2_P1.3mm_Bridged2Bar_Pad1.0x1.5mm
JP102, JP103, JP108: Jumper_Open; SolderJumper-2_P1.3mm_Open_Pad1.0x1.5mm
JP107: SIDE_BIT; SolderJumper-2_P1.3mm_Open_Pad1.0x1.5mm
JP109: TERM; SolderJumper-2_P1.3mm_Open_Pad1.0x1.5mm
L101: 4.7u; INDPM4441X200N; Manufacturer_Part_Number SRP4020TA-4R7M
R101: 30.9k; R_0402_1005Metric
R102: 10k; R_0402_1005Metric
R103: 1k; R_0402_1005Metric
R104: 120; R_0402_1005Metric
TP101: CANH; TestPoint_Pad_D1.0mm
TP102: CANL; TestPoint_Pad_D1.0mm
TP103: VBAT; TestPoint_Pad_D1.0mm
TP104: 3V3; TestPoint_Pad_D1.0mm
TP105: GND; TestPoint_Pad_D1.0mm

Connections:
+3V3: C102.2, J104.1, JP101.1 (A), JP102.2 (B), JP103.1 (A), JP104.1 (A), JP105.1 (A), JP106.1 (A), JP107.1 (A), L101.2, R101.1, R103.2, TP104.1 (1_1); also elsewhere on the board
/CAN_H: IC102.1 (A_1), J101.1, J102.1, R104.2, TP101.1 (1_1); also elsewhere on the board
/CAN_L: IC102.2 (A_2), J101.2, J102.2, JP109.2 (B), TP102.1 (1_1); also elsewhere on the board
/CAN_TERM: JP109.1 (A), R104.1
/Leg_A/LEG_ID_B0: JP101.2 (B); also elsewhere on the board
/Leg_A/LEG_ID_B1: JP102.1 (A); also elsewhere on the board
/Leg_B/LEG_ID_B0: JP103.2 (B); also elsewhere on the board
/Leg_B/LEG_ID_B1: JP104.2 (B); also elsewhere on the board
/Leg_C/LEG_ID_B0: JP106.2 (B); also elsewhere on the board
/Leg_C/LEG_ID_B1: JP105.2 (B); also elsewhere on the board
/PSU_FB: IC101.8 (FB), R101.2, R102.1
/SIDE_BIT: JP107.2 (B); also elsewhere on the board
/SW: C101.2, IC101.5 (SW), L101.1
/VBAT: C103.2, C104.2, C106.1, D101.1 (K), IC101.3 (VIN), J103.1, TP103.1 (1_1); also elsewhere on the board
/~ESTOP_N: J101.4, J102.4; also elsewhere on the board
GND: C102.1, C103.1, C104.1, C105.1, C106.2, D101.2 (A), D102.1 (K), IC101.4 (GND), IC102.3 (A_3), J101.3, J102.3, J103.2, J104.2, JP108.1 (A), R102.2, TP105.1 (1_1); also elsewhere on the board
unnamed: D102.2 (A), R103.1
unnamed: C101.1, IC101.6 (BST)
unnamed: IC101.2 (EN), JP108.2 (B)
unnamed: C105.2, IC101.7 (SS)

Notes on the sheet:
3.3V Step-Down Converter

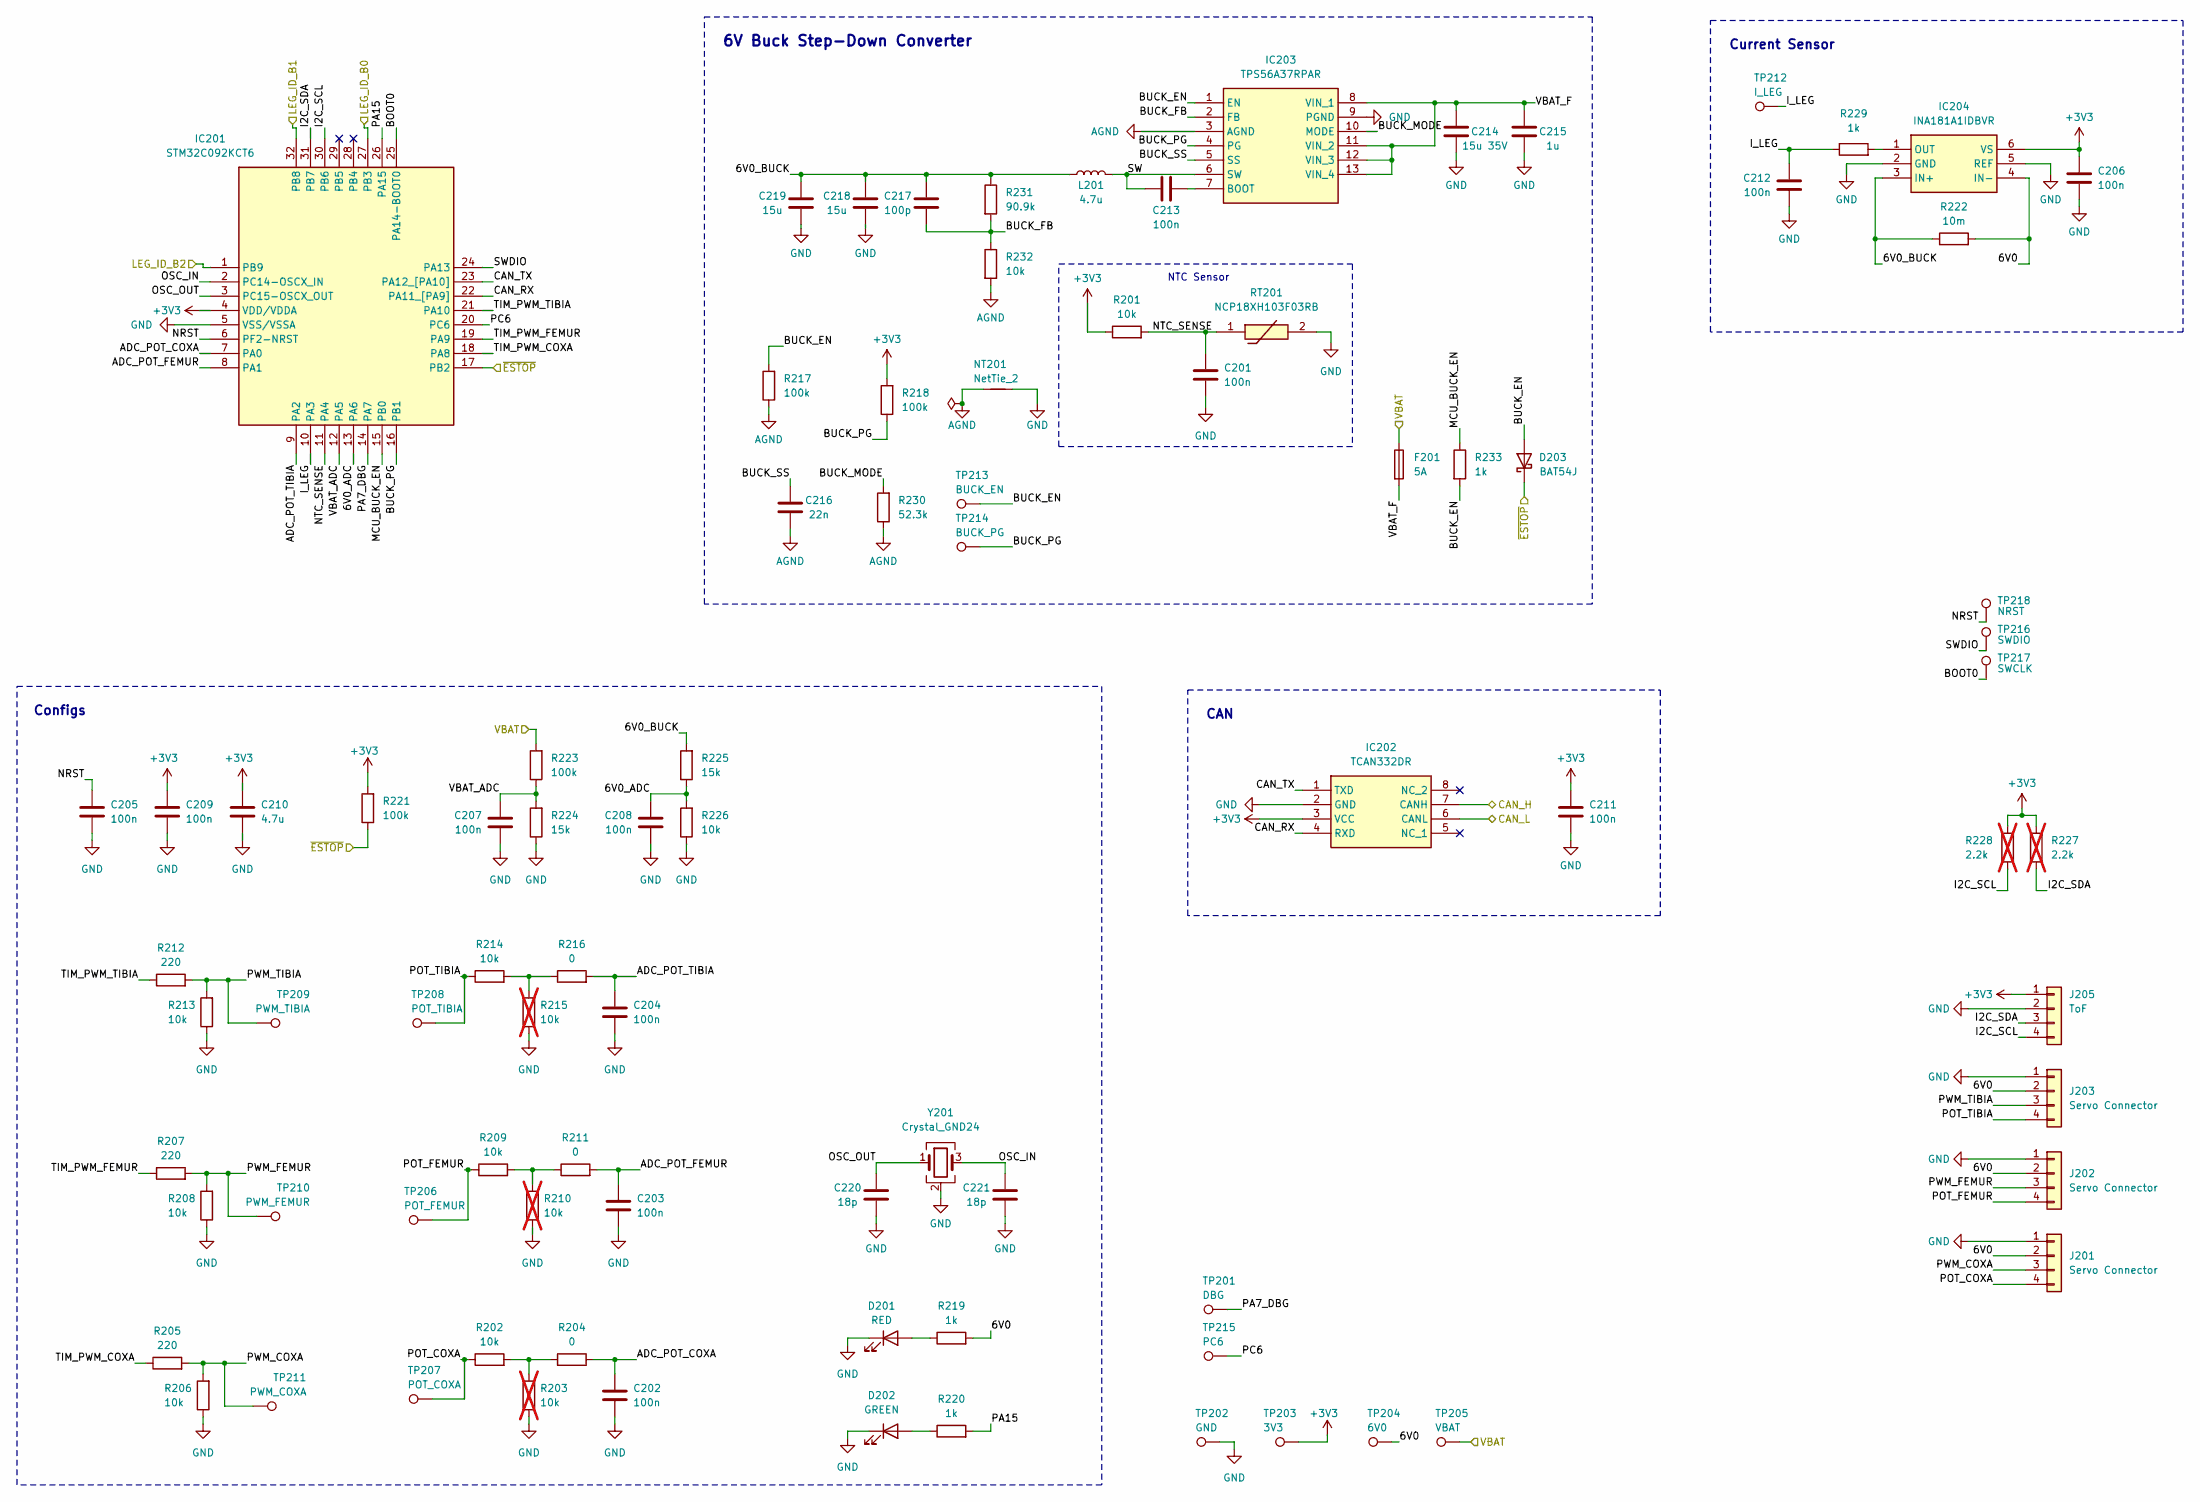
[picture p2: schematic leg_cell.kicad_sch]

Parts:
C201, C202, C203, C204, C205, C206, C207, C208, C209, C211, C212, C213: 100n; C_0402_1005Metric
C210: 4.7u; C_0805_2012Metric
C214: 15u 35V; C_1206_3216Metric
C215: 1u; C_0805_2012Metric
C216: 22n; C_0402_1005Metric
C217: 100p; C_0402_1005Metric
C218, C219: 15u; C_1206_3216Metric
C220, C221: 18p; C_0402_1005Metric
D201: RED; LED_0805_2012Metric
D202: GREEN; LED_0805_2012Metric
D203: BAT54J; D_SOD-323F
F201: 5A; Fuse_1206_3216Metric
IC201: STM32C092KCT6; QFP80P900X900X160-32N; Mouser Part Number 511-STM32C092KCT6
IC202: TCAN332DR; SOIC127P600X175-8N; Mouser Part Number 595-TCAN332DR
IC203: TPS56A37RPAR; Mouser Part Number 595-TPS56A37RPAR
IC204: INA181A1IDBVR; SOT95P280X145-6N; Mouser Part Number 595-INA181A1IDBVR
J201, J202, J203: Servo Connector; PinHeader_1x04_P2.54mm_Vertical_Tile
J205: ToF; PinHeader_1x04_P2.54mm_Vertical_Tile
L201: 4.7u; INDPM7973X540N; Manufacturer_Part_Number SRP7050WA-4R7M
NT201: NetTie_2; NetTie-2_SMD_Pad0.5mm
R201, R202, R206, R208, R209, R213, R214, R226, R232: 10k; R_0402_1005Metric
R203, R210, R215: 10k; R_0402_1005Metric; not fitted
R204, R211, R216: 0; R_0402_1005Metric
R205, R207, R212: 220; R_0402_1005Metric
R217, R218, R221, R223: 100k; R_0402_1005Metric
R219, R220, R229, R233: 1k; R_0402_1005Metric
R222: 10m; R_2512_6332Metric
R224, R225: 15k; R_0402_1005Metric
R227, R228: 2.2k; R_0402_1005Metric; not fitted
R230: 52.3k; R_0402_1005Metric
R231: 90.9k; R_0402_1005Metric
RT201: NCP18XH103F03RB; THRMC1608X95N; Mouser Part Number 81-NCP18XH103F03RB
TP201: DBG; TestPoint_Pad_D1.0mm
TP202: GND; TestPoint_Pad_D1.0mm
TP203: 3V3; TestPoint_Pad_D1.0mm
TP204: 6V0; TestPoint_Pad_D1.0mm
TP205: VBAT; TestPoint_Pad_D1.0mm
TP206: POT_FEMUR; TestPoint_Pad_D1.0mm
TP207: POT_COXA; TestPoint_Pad_D1.0mm
TP208: POT_TIBIA; TestPoint_Pad_D1.0mm
TP209: PWM_TIBIA; TestPoint_Pad_D1.0mm
TP210: PWM_FEMUR; TestPoint_Pad_D1.0mm
TP211: PWM_COXA; TestPoint_Pad_D1.0mm
TP212: I_LEG; TestPoint_Pad_D1.0mm
TP213: BUCK_EN; TestPoint_Pad_D1.0mm
TP214: BUCK_PG; TestPoint_Pad_D1.0mm
TP215: PC6; TestPoint_Pad_D1.0mm
TP216: SWDIO; TestPoint_Pad_D1.0mm
TP217: SWCLK; TestPoint_Pad_D1.0mm
TP218: NRST; TestPoint_Pad_D1.0mm
Y201: Crystal_GND24; Crystal_SMD_2016-4Pin_2.0x1.6mm; Manufacturer_Part_Number K2B400001210

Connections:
+3V3: C206.2, C209.2, C210.2, C211.2, IC201.4 (VDD/VDDA), IC202.3 (VCC), IC204.6 (VS), J205.1, R201.1, R218.2, R221.2, R227.2, R228.1, TP203.1 (1_1); also elsewhere on the board
/CAN_H: IC202.7 (CANH); also elsewhere on the board
/CAN_L: IC202.6 (CANL); also elsewhere on the board
/Leg_A/6V0: IC204.4 (IN-), J201.2, J202.2, J203.2, R219.2, R222.2, TP204.1 (1_1)
/Leg_A/6V0_ADC: C208.1, IC201.13 (PA6), R225.1, R226.2
/Leg_A/6V0_BUCK: C217.2, C218.2, C219.2, IC204.3 (IN+), L201.1, R222.1, R225.2, R231.1
/Leg_A/ADC_POT_COXA: C202.1, IC201.7 (PA0), R204.1
/Leg_A/ADC_POT_FEMUR: C203.1, IC201.8 (PA1), R211.2
/Leg_A/ADC_POT_TIBIA: C204.1, IC201.9 (PA2), R216.2
/Leg_A/AGND: C216.2, IC203.3 (AGND), NT201.1, R217.1, R230.1, R232.2
/Leg_A/BOOT0: IC201.25 (PA14-BOOT0), TP217.1 (1_1)
/Leg_A/BUCK_EN: D203.2 (A), IC203.1 (EN), R217.2, R233.2, TP213.1 (1_1)
/Leg_A/BUCK_FB: C217.1, IC203.2 (FB), R231.2, R232.1
/Leg_A/BUCK_MODE: IC203.10 (MODE), R230.2
/Leg_A/BUCK_PG: IC201.16 (PB1), IC203.4 (PG), R218.1, TP214.1 (1_1)
/Leg_A/BUCK_SS: C216.1, IC203.5 (SS)
/Leg_A/CAN_RX: IC201.22 (PA11_[PA9]), IC202.4 (RXD)
/Leg_A/CAN_TX: IC201.23 (PA12_[PA10]), IC202.1 (TXD)
/Leg_A/I2C_SCL: IC201.30 (PB6), J205.4, R228.2
/Leg_A/I2C_SDA: IC201.31 (PB7), J205.3, R227.1
/Leg_A/I_LEG: C212.1, IC201.10 (PA3), R229.1, TP212.1 (1_1)
/Leg_A/LEG_ID_B0: IC201.27 (PB3); also elsewhere on the board
/Leg_A/LEG_ID_B1: IC201.32 (PB8); also elsewhere on the board
/Leg_A/MCU_BUCK_EN: IC201.15 (PB0), R233.1
/Leg_A/NRST: C205.2, IC201.6 (PF2-NRST), TP218.1 (1_1)
/Leg_A/NTC_SENSE: C201.1, IC201.11 (PA4), R201.2, RT201.1
/Leg_A/OSC_IN: C221.2, IC201.2 (PC14-OSCX_IN), Y201.3
/Leg_A/OSC_OUT: C220.2, IC201.3 (PC15-OSCX_OUT), Y201.1
/Leg_A/PA7_DBG: IC201.14 (PA7), TP201.1 (1_1)
/Leg_A/PA15: IC201.26 (PA15), R220.2
/Leg_A/PC6: IC201.20 (PC6), TP215.1 (1_1)
/Leg_A/POT_COXA: J201.4, R202.1, TP207.1 (1_1)
/Leg_A/POT_FEMUR: J202.4, R209.1, TP206.1 (1_1)
/Leg_A/POT_TIBIA: J203.4, R214.1, TP208.1 (1_1)
/Leg_A/PWM_COXA: J201.3, R205.2, R206.2, TP211.1 (1_1)
/Leg_A/PWM_FEMUR: J202.3, R207.2, R208.2, TP210.1 (1_1)
/Leg_A/PWM_TIBIA: J203.3, R212.2, R213.2, TP209.1 (1_1)
/Leg_A/SW: C213.2, IC203.6 (SW), L201.2
/Leg_A/SWDIO: IC201.24 (PA13), TP216.1 (1_1)
/Leg_A/TIM_PWM_COXA: IC201.18 (PA8), R205.1
/Leg_A/TIM_PWM_FEMUR: IC201.19 (PA9), R207.1
/Leg_A/TIM_PWM_TIBIA: IC201.21 (PA10), R212.1
/Leg_A/VBAT_ADC: C207.1, IC201.12 (PA5), R223.1, R224.2
/Leg_A/VBAT_F: C214.1, C215.1, F201.2, IC203.8 (VIN_1), IC203.11 (VIN_2), IC203.12 (VIN_3), IC203.13 (VIN_4)
/SIDE_BIT: IC201.1 (PB9); also elsewhere on the board
/VBAT: F201.1, R223.2, TP205.1 (1_1); also elsewhere on the board
/~ESTOP_N: D203.1 (K), IC201.17 (PB2), R221.1; also elsewhere on the board
GND: C201.2, C202.2, C203.2, C204.2, C205.1, C206.1, C207.2, C208.2, C209.1, C210.1, C211.1, C212.2, C214.2, C215.2, C218.1, C219.1, C220.1, C221.1, D201.1 (K), D202.1 (K), IC201.5 (VSS/VSSA), IC202.2 (GND), IC203.9 (PGND), IC204.2 (GND), IC204.5 (REF), J201.1, J202.1, J203.1, J205.2, NT201.2, R203.1, R206.1, R208.1, R210.1, R213.1, R215.1, R224.1, R226.1, RT201.2, TP202.1 (1_1), Y201.2 (G), Y201.4 (G); also elsewhere on the board
unnamed: D201.2 (A), R219.1
unnamed: D202.2 (A), R220.1
unnamed: C213.1, IC203.7 (BOOT)
unnamed: IC204.1 (OUT), R229.2
unnamed: R202.2, R203.2, R204.2
unnamed: R209.2, R210.2, R211.1
unnamed: R214.2, R215.2, R216.1

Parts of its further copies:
C301, C302, C303, C304, C305, C306, C307, C308, C309, C311, C312, C313, C401, C402, C403, C404, C405, C406, C407, C408, C409, C411, C412, C413: 100n; C_0402_1005Metric
C310, C410: 4.7u; C_0805_2012Metric
C314, C414: 15u 35V; C_1206_3216Metric
C315, C415: 1u; C_0805_2012Metric
C316, C416: 22n; C_0402_1005Metric
C317, C417: 100p; C_0402_1005Metric
C318, C319, C418, C419: 15u; C_1206_3216Metric
C320, C321, C420, C421: 18p; C_0402_1005Metric
D301, D401: RED; LED_0805_2012Metric
D302, D402: GREEN; LED_0805_2012Metric
D303, D403: BAT54J; D_SOD-323F
F301, F401: 5A; Fuse_1206_3216Metric
IC301, IC401: STM32C092KCT6; QFP80P900X900X160-32N; Mouser Part Number 511-STM32C092KCT6
IC302, IC402: TCAN332DR; SOIC127P600X175-8N; Mouser Part Number 595-TCAN332DR
IC303, IC403: TPS56A37RPAR; Mouser Part Number 595-TPS56A37RPAR
IC304, IC404: INA181A1IDBVR; SOT95P280X145-6N; Mouser Part Number 595-INA181A1IDBVR
J301, J302, J303, J401, J402, J403: Servo Connector; PinHeader_1x04_P2.54mm_Vertical_Tile
J305, J405: ToF; PinHeader_1x04_P2.54mm_Vertical_Tile
L301, L401: 4.7u; INDPM7973X540N; Manufacturer_Part_Number SRP7050WA-4R7M
NT301, NT401: NetTie_2; NetTie-2_SMD_Pad0.5mm
R301, R302, R306, R308, R309, R313, R314, R326, R332, R401, R402, R406, R408, R409, R413, R414, R426, R432: 10k; R_0402_1005Metric
R303, R310, R315, R403, R410, R415: 10k; R_0402_1005Metric; not fitted
R304, R311, R316, R404, R411, R416: 0; R_0402_1005Metric
R305, R307, R312, R405, R407, R412: 220; R_0402_1005Metric
R317, R318, R321, R323, R417, R418, R421, R423: 100k; R_0402_1005Metric
R319, R320, R329, R333, R419, R420, R429, R433: 1k; R_0402_1005Metric
R322, R422: 10m; R_2512_6332Metric
R324, R325, R424, R425: 15k; R_0402_1005Metric
R327, R328, R427, R428: 2.2k; R_0402_1005Metric; not fitted
R330, R430: 52.3k; R_0402_1005Metric
R331, R431: 90.9k; R_0402_1005Metric
RT301, RT401: NCP18XH103F03RB; THRMC1608X95N; Mouser Part Number 81-NCP18XH103F03RB
TP301, TP401: DBG; TestPoint_Pad_D1.0mm
TP302, TP402: GND; TestPoint_Pad_D1.0mm
TP303, TP403: 3V3; TestPoint_Pad_D1.0mm
TP304, TP404: 6V0; TestPoint_Pad_D1.0mm
TP305, TP405: VBAT; TestPoint_Pad_D1.0mm
TP306, TP406: POT_FEMUR; TestPoint_Pad_D1.0mm
TP307, TP407: POT_COXA; TestPoint_Pad_D1.0mm
TP308, TP408: POT_TIBIA; TestPoint_Pad_D1.0mm
TP309, TP409: PWM_TIBIA; TestPoint_Pad_D1.0mm
TP310, TP410: PWM_FEMUR; TestPoint_Pad_D1.0mm
TP311, TP411: PWM_COXA; TestPoint_Pad_D1.0mm
TP312, TP412: I_LEG; TestPoint_Pad_D1.0mm
TP313, TP413: BUCK_EN; TestPoint_Pad_D1.0mm
TP314, TP414: BUCK_PG; TestPoint_Pad_D1.0mm
TP315, TP415: PC6; TestPoint_Pad_D1.0mm
TP316, TP416: SWDIO; TestPoint_Pad_D1.0mm
TP317, TP417: SWCLK; TestPoint_Pad_D1.0mm
TP318, TP418: NRST; TestPoint_Pad_D1.0mm
Y301, Y401: Crystal_GND24; Crystal_SMD_2016-4Pin_2.0x1.6mm; Manufacturer_Part_Number K2B400001210

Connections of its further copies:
+3V3: C306.2, C309.2, C310.2, C311.2, C406.2, C409.2, C410.2, C411.2, IC301.4 (VDD/VDDA), IC302.3 (VCC), IC304.6 (VS), IC401.4 (VDD/VDDA), IC402.3 (VCC), IC404.6 (VS), J305.1, J405.1, R301.1, R318.2, R321.2, R327.2, R328.1, R401.1, R418.2, R421.2, R427.2, R428.1, TP303.1 (1_1), TP403.1 (1_1); also elsewhere on the board
/CAN_H: IC302.7 (CANH), IC402.7 (CANH); also elsewhere on the board
/CAN_L: IC302.6 (CANL), IC402.6 (CANL); also elsewhere on the board
/Leg_B/6V0: IC304.4 (IN-), J301.2, J302.2, J303.2, R319.2, R322.2, TP304.1 (1_1)
/Leg_B/6V0_ADC: C308.1, IC301.13 (PA6), R325.1, R326.2
/Leg_B/6V0_BUCK: C317.2, C318.2, C319.2, IC304.3 (IN+), L301.1, R322.1, R325.2, R331.1
/Leg_B/ADC_POT_COXA: C302.1, IC301.7 (PA0), R304.1
/Leg_B/ADC_POT_FEMUR: C303.1, IC301.8 (PA1), R311.2
/Leg_B/ADC_POT_TIBIA: C304.1, IC301.9 (PA2), R316.2
/Leg_B/AGND: C316.2, IC303.3 (AGND), NT301.1, R317.1, R330.1, R332.2
/Leg_B/BOOT0: IC301.25 (PA14-BOOT0), TP317.1 (1_1)
/Leg_B/BUCK_EN: D303.2 (A), IC303.1 (EN), R317.2, R333.2, TP313.1 (1_1)
/Leg_B/BUCK_FB: C317.1, IC303.2 (FB), R331.2, R332.1
/Leg_B/BUCK_MODE: IC303.10 (MODE), R330.2
/Leg_B/BUCK_PG: IC301.16 (PB1), IC303.4 (PG), R318.1, TP314.1 (1_1)
/Leg_B/BUCK_SS: C316.1, IC303.5 (SS)
/Leg_B/CAN_RX: IC301.22 (PA11_[PA9]), IC302.4 (RXD)
/Leg_B/CAN_TX: IC301.23 (PA12_[PA10]), IC302.1 (TXD)
/Leg_B/I2C_SCL: IC301.30 (PB6), J305.4, R328.2
/Leg_B/I2C_SDA: IC301.31 (PB7), J305.3, R327.1
/Leg_B/I_LEG: C312.1, IC301.10 (PA3), R329.1, TP312.1 (1_1)
/Leg_B/LEG_ID_B0: IC301.27 (PB3); also elsewhere on the board
/Leg_B/LEG_ID_B1: IC301.32 (PB8); also elsewhere on the board
/Leg_B/MCU_BUCK_EN: IC301.15 (PB0), R333.1
/Leg_B/NRST: C305.2, IC301.6 (PF2-NRST), TP318.1 (1_1)
/Leg_B/NTC_SENSE: C301.1, IC301.11 (PA4), R301.2, RT301.1
/Leg_B/OSC_IN: C321.2, IC301.2 (PC14-OSCX_IN), Y301.3
/Leg_B/OSC_OUT: C320.2, IC301.3 (PC15-OSCX_OUT), Y301.1
/Leg_B/PA7_DBG: IC301.14 (PA7), TP301.1 (1_1)
/Leg_B/PA15: IC301.26 (PA15), R320.2
/Leg_B/PC6: IC301.20 (PC6), TP315.1 (1_1)
/Leg_B/POT_COXA: J301.4, R302.1, TP307.1 (1_1)
/Leg_B/POT_FEMUR: J302.4, R309.1, TP306.1 (1_1)
/Leg_B/POT_TIBIA: J303.4, R314.1, TP308.1 (1_1)
/Leg_B/PWM_COXA: J301.3, R305.2, R306.2, TP311.1 (1_1)
/Leg_B/PWM_FEMUR: J302.3, R307.2, R308.2, TP310.1 (1_1)
/Leg_B/PWM_TIBIA: J303.3, R312.2, R313.2, TP309.1 (1_1)
/Leg_B/SW: C313.2, IC303.6 (SW), L301.2
/Leg_B/SWDIO: IC301.24 (PA13), TP316.1 (1_1)
/Leg_B/TIM_PWM_COXA: IC301.18 (PA8), R305.1
/Leg_B/TIM_PWM_FEMUR: IC301.19 (PA9), R307.1
/Leg_B/TIM_PWM_TIBIA: IC301.21 (PA10), R312.1
/Leg_B/VBAT_ADC: C307.1, IC301.12 (PA5), R323.1, R324.2
/Leg_B/VBAT_F: C314.1, C315.1, F301.2, IC303.8 (VIN_1), IC303.11 (VIN_2), IC303.12 (VIN_3), IC303.13 (VIN_4)
/Leg_C/6V0: IC404.4 (IN-), J401.2, J402.2, J403.2, R419.2, R422.2, TP404.1 (1_1)
/Leg_C/6V0_ADC: C408.1, IC401.13 (PA6), R425.1, R426.2
/Leg_C/6V0_BUCK: C417.2, C418.2, C419.2, IC404.3 (IN+), L401.1, R422.1, R425.2, R431.1
/Leg_C/ADC_POT_COXA: C402.1, IC401.7 (PA0), R404.1
/Leg_C/ADC_POT_FEMUR: C403.1, IC401.8 (PA1), R411.2
/Leg_C/ADC_POT_TIBIA: C404.1, IC401.9 (PA2), R416.2
/Leg_C/AGND: C416.2, IC403.3 (AGND), NT401.1, R417.1, R430.1, R432.2
/Leg_C/BOOT0: IC401.25 (PA14-BOOT0), TP417.1 (1_1)
/Leg_C/BUCK_EN: D403.2 (A), IC403.1 (EN), R417.2, R433.2, TP413.1 (1_1)
/Leg_C/BUCK_FB: C417.1, IC403.2 (FB), R431.2, R432.1
/Leg_C/BUCK_MODE: IC403.10 (MODE), R430.2
/Leg_C/BUCK_PG: IC401.16 (PB1), IC403.4 (PG), R418.1, TP414.1 (1_1)
/Leg_C/BUCK_SS: C416.1, IC403.5 (SS)
/Leg_C/CAN_RX: IC401.22 (PA11_[PA9]), IC402.4 (RXD)
/Leg_C/CAN_TX: IC401.23 (PA12_[PA10]), IC402.1 (TXD)
/Leg_C/I2C_SCL: IC401.30 (PB6), J405.4, R428.2
/Leg_C/I2C_SDA: IC401.31 (PB7), J405.3, R427.1
/Leg_C/I_LEG: C412.1, IC401.10 (PA3), R429.1, TP412.1 (1_1)
/Leg_C/LEG_ID_B0: IC401.27 (PB3); also elsewhere on the board
/Leg_C/LEG_ID_B1: IC401.32 (PB8); also elsewhere on the board
/Leg_C/MCU_BUCK_EN: IC401.15 (PB0), R433.1
/Leg_C/NRST: C405.2, IC401.6 (PF2-NRST), TP418.1 (1_1)
/Leg_C/NTC_SENSE: C401.1, IC401.11 (PA4), R401.2, RT401.1
/Leg_C/OSC_IN: C421.2, IC401.2 (PC14-OSCX_IN), Y401.3
/Leg_C/OSC_OUT: C420.2, IC401.3 (PC15-OSCX_OUT), Y401.1
/Leg_C/PA7_DBG: IC401.14 (PA7), TP401.1 (1_1)
/Leg_C/PA15: IC401.26 (PA15), R420.2
/Leg_C/PC6: IC401.20 (PC6), TP415.1 (1_1)
/Leg_C/POT_COXA: J401.4, R402.1, TP407.1 (1_1)
/Leg_C/POT_FEMUR: J402.4, R409.1, TP406.1 (1_1)
/Leg_C/POT_TIBIA: J403.4, R414.1, TP408.1 (1_1)
/Leg_C/PWM_COXA: J401.3, R405.2, R406.2, TP411.1 (1_1)
/Leg_C/PWM_FEMUR: J402.3, R407.2, R408.2, TP410.1 (1_1)
/Leg_C/PWM_TIBIA: J403.3, R412.2, R413.2, TP409.1 (1_1)
/Leg_C/SW: C413.2, IC403.6 (SW), L401.2
/Leg_C/SWDIO: IC401.24 (PA13), TP416.1 (1_1)
/Leg_C/TIM_PWM_COXA: IC401.18 (PA8), R405.1
/Leg_C/TIM_PWM_FEMUR: IC401.19 (PA9), R407.1
/Leg_C/TIM_PWM_TIBIA: IC401.21 (PA10), R412.1
/Leg_C/VBAT_ADC: C407.1, IC401.12 (PA5), R423.1, R424.2
/Leg_C/VBAT_F: C414.1, C415.1, F401.2, IC403.8 (VIN_1), IC403.11 (VIN_2), IC403.12 (VIN_3), IC403.13 (VIN_4)
/SIDE_BIT: IC301.1 (PB9), IC401.1 (PB9); also elsewhere on the board
/VBAT: F301.1, F401.1, R323.2, R423.2, TP305.1 (1_1), TP405.1 (1_1); also elsewhere on the board
/~ESTOP_N: D303.1 (K), D403.1 (K), IC301.17 (PB2), IC401.17 (PB2), R321.1, R421.1; also elsewhere on the board
GND: C301.2, C302.2, C303.2, C304.2, C305.1, C306.1, C307.2, C308.2, C309.1, C310.1, C311.1, C312.2, C314.2, C315.2, C318.1, C319.1, C320.1, C321.1, C401.2, C402.2, C403.2, C404.2, C405.1, C406.1, C407.2, C408.2, C409.1, C410.1, C411.1, C412.2, C414.2, C415.2, C418.1, C419.1, C420.1, C421.1, D301.1 (K), D302.1 (K), D401.1 (K), D402.1 (K), IC301.5 (VSS/VSSA), IC302.2 (GND), IC303.9 (PGND), IC304.2 (GND), IC304.5 (REF), IC401.5 (VSS/VSSA), IC402.2 (GND), IC403.9 (PGND), IC404.2 (GND), IC404.5 (REF), J301.1, J302.1, J303.1, J305.2, J401.1, J402.1, J403.1, J405.2, NT301.2, NT401.2, R303.1, R306.1, R308.1, R310.1, R313.1, R315.1, R324.1, R326.1, R403.1, R406.1, R408.1, R410.1, R413.1, R415.1, R424.1, R426.1, RT301.2, RT401.2, TP302.1 (1_1), TP402.1 (1_1), Y301.2 (G), Y301.4 (G), Y401.2 (G), Y401.4 (G); also elsewhere on the board
unnamed: D301.2 (A), R319.1
unnamed: D302.2 (A), R320.1
unnamed: D401.2 (A), R419.1
unnamed: D402.2 (A), R420.1
unnamed: C313.1, IC303.7 (BOOT)
unnamed: IC304.1 (OUT), R329.2
unnamed: C413.1, IC403.7 (BOOT)
unnamed: IC404.1 (OUT), R429.2
unnamed: R302.2, R303.2, R304.2
unnamed: R309.2, R310.2, R311.1
unnamed: R314.2, R315.2, R316.1
unnamed: R402.2, R403.2, R404.2
unnamed: R409.2, R410.2, R411.1
unnamed: R414.2, R415.2, R416.1

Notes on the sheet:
6V Buck Step-Down Converter
CAN
Configs
Current Sensor
NTC Sensor

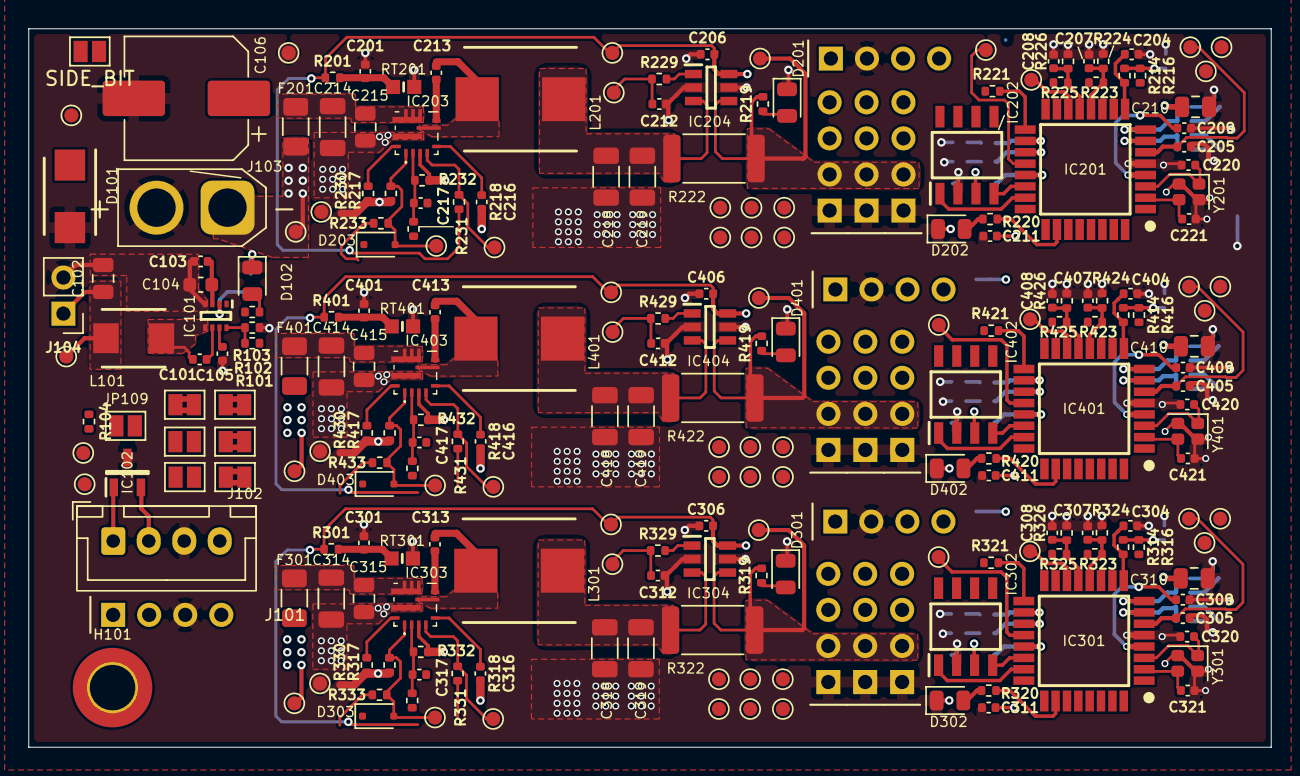
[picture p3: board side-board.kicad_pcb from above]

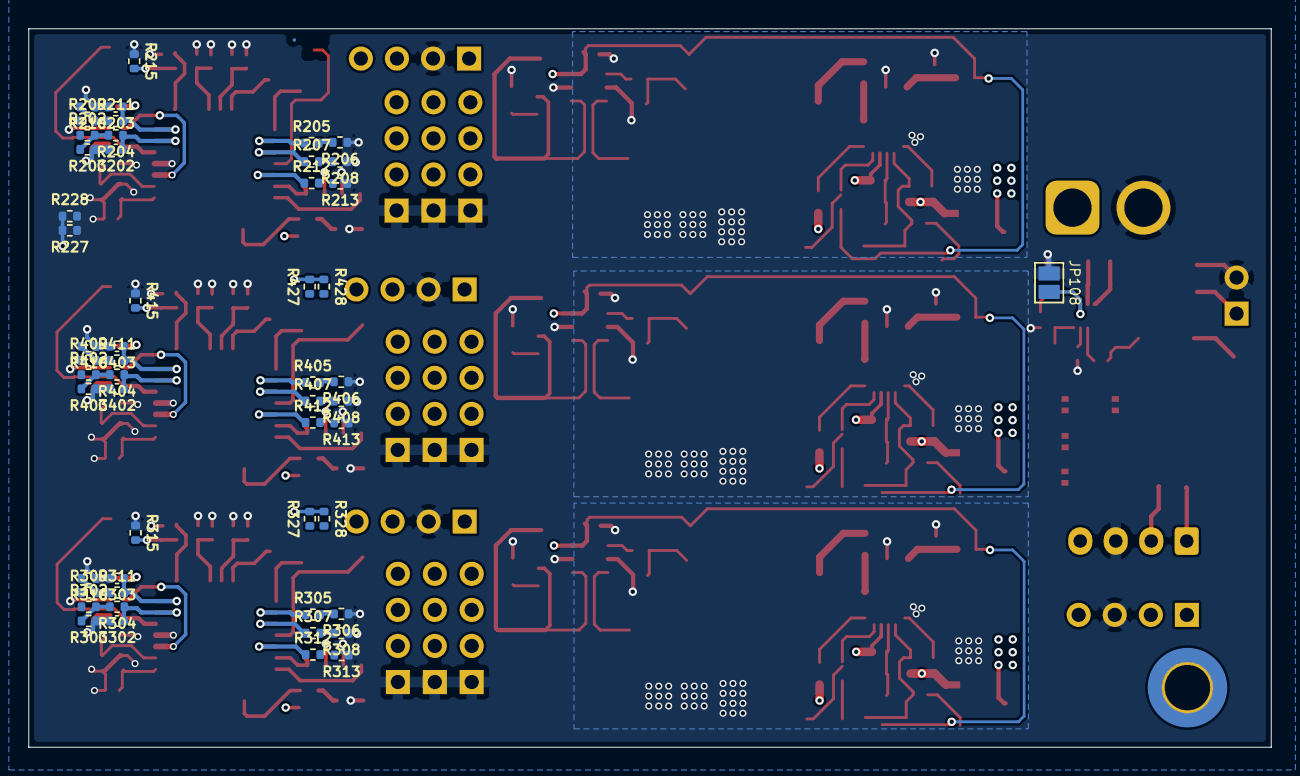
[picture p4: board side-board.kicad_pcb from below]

Board: 4 copper layers, 87.5 x 50.6 mm, 298 parts (52 on the bottom side), 158 nets.

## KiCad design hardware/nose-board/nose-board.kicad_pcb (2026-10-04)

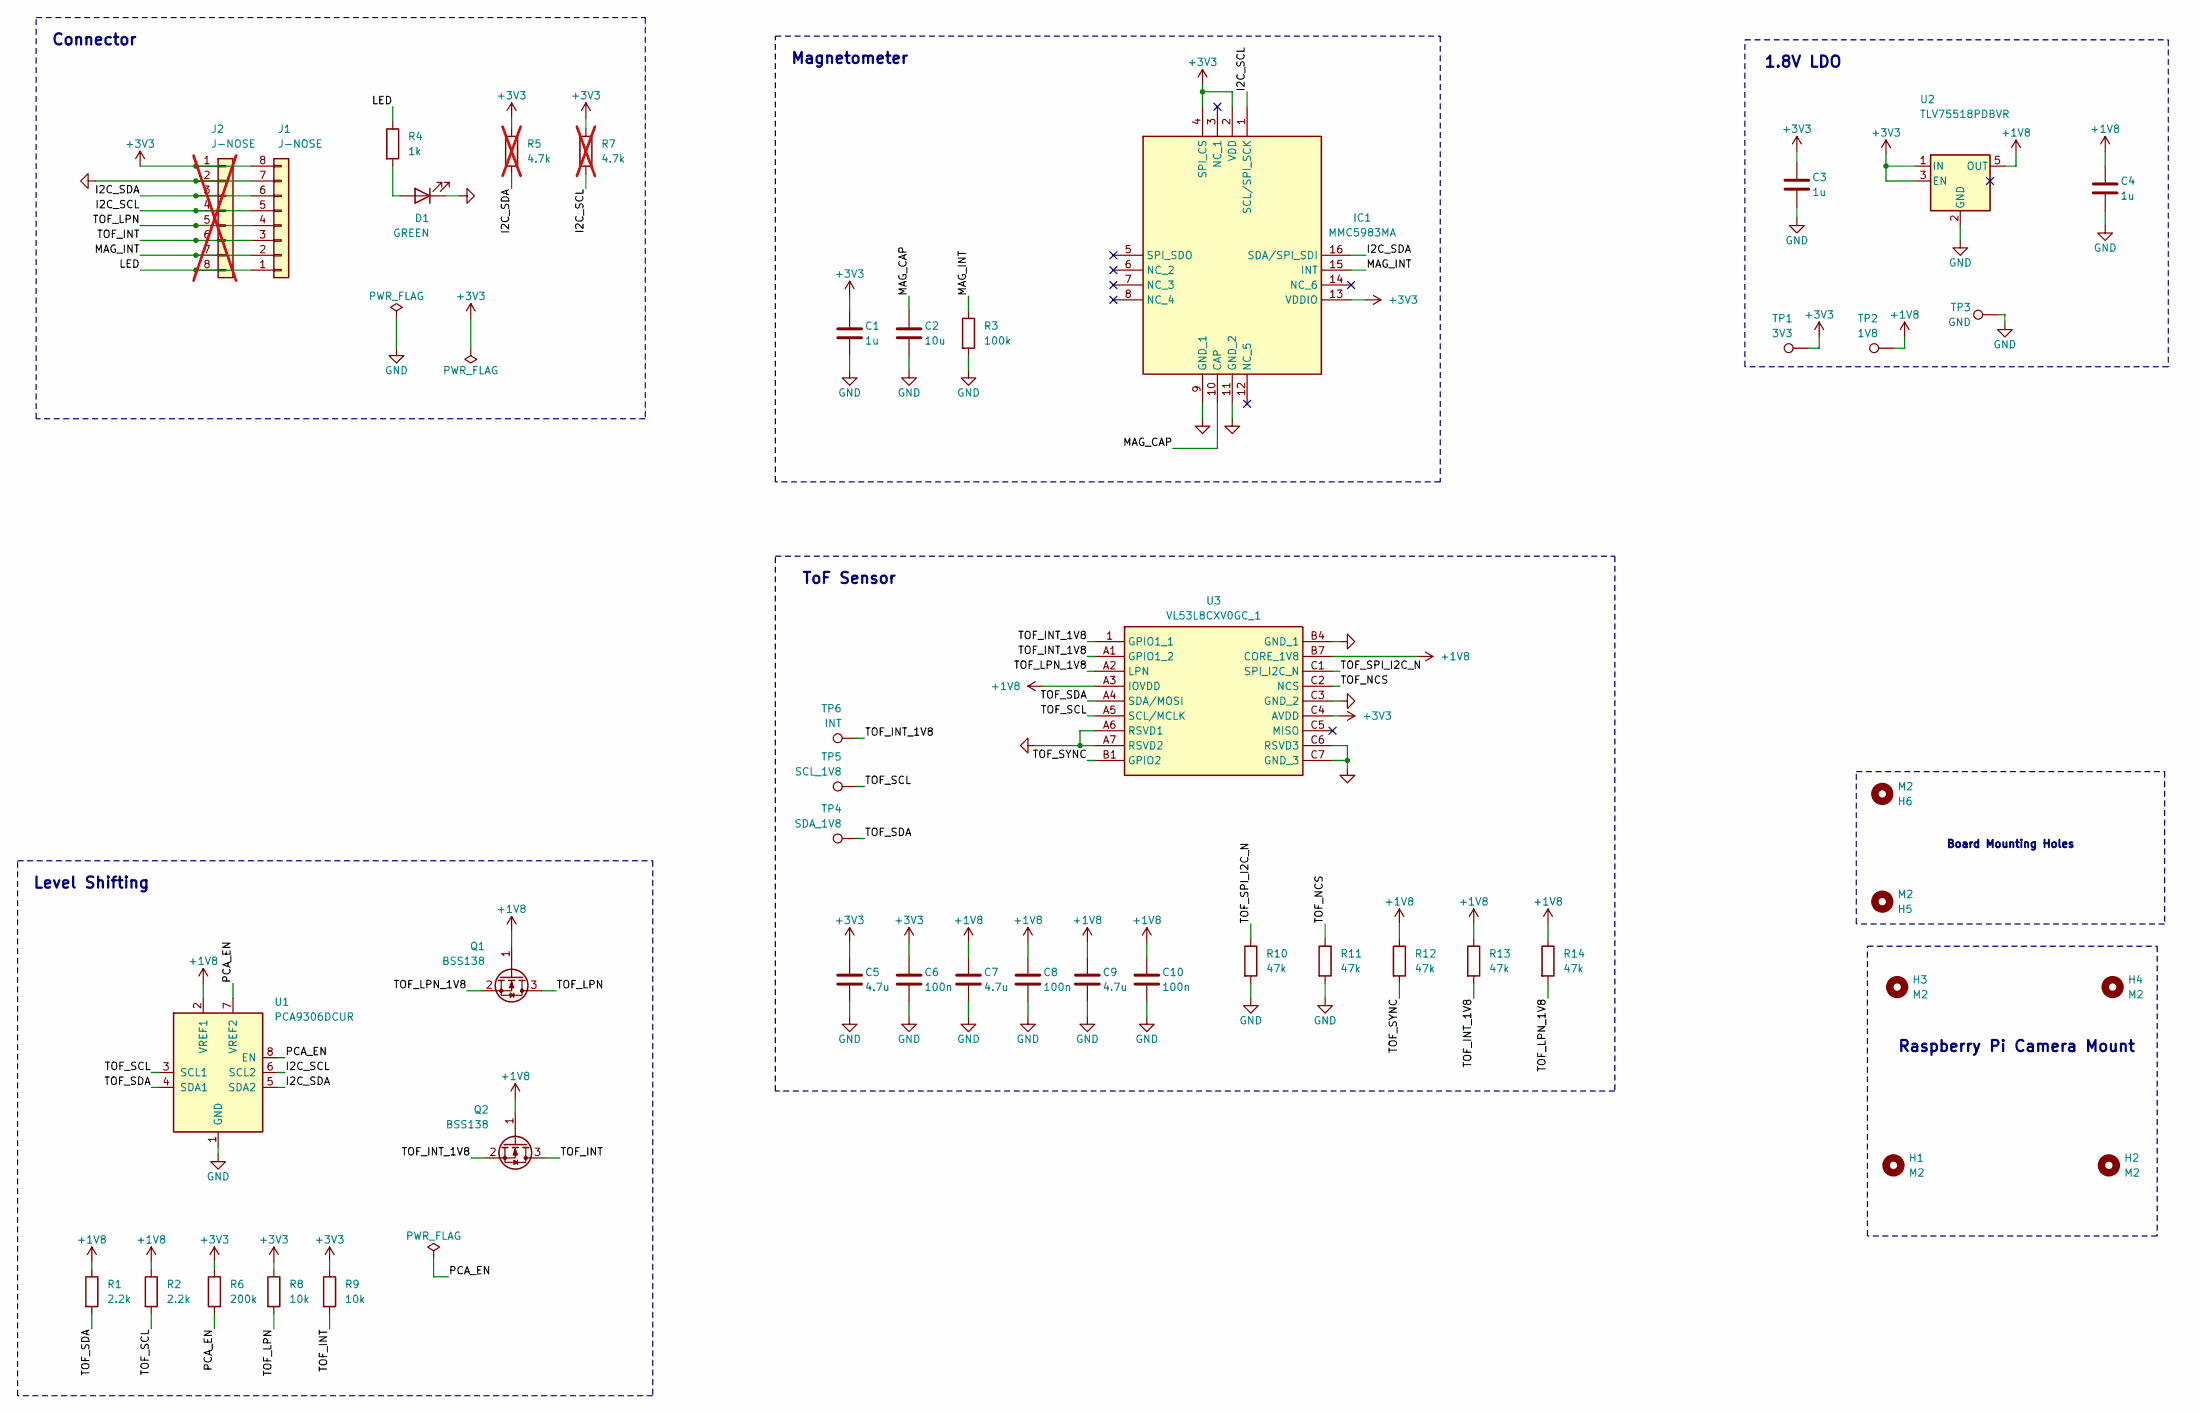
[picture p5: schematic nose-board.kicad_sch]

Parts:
C1, C3, C4: 1u; C_0603_1608Metric
C2: 10u; C_0805_2012Metric
C5, C7, C9: 4.7u; C_0805_2012Metric
C6, C8, C10: 100n; C_0603_1608Metric
D1: GREEN; LED_0603_1608Metric
H1, H2, H3, H4: M2; MountingHole_2.2mm_M2
H5, H6: M2; MountingHole_2.2mm_M2_Pad_TopBottom
IC1: MMC5983MA; Mouser Part Number 438-MMC5983MA
J1: J-NOSE; JST_GH_SM08B-GHS-TB_1x08-1MP_P1.25mm_Horizontal
J2: J-NOSE; JST_GH_SM08B-GHS-TB_1x08-1MP_P1.25mm_Horizontal; not fitted
Q1, Q2: BSS138; SOT-23
R1, R2: 2.2k; R_0603_1608Metric
R3: 100k; R_0603_1608Metric
R4: 1k; R_0603_1608Metric
R5, R7: 4.7k; R_0603_1608Metric; not fitted
R6: 200k; R_0603_1608Metric
R8, R9: 10k; R_0603_1608Metric
R10, R11, R12, R13, R14: 47k; R_0603_1608Metric
TP1: 3V3; TestPoint_Pad_D2.0mm
TP2: 1V8; TestPoint_Pad_D2.0mm
TP3: GND; TestPoint_Pad_D2.0mm
TP4: SDA_1V8; TestPoint_Pad_D2.0mm
TP5: SCL_1V8; TestPoint_Pad_D2.0mm
TP6: INT; TestPoint_Pad_D2.0mm
U1: PCA9306DCUR; VSSOP-8_2.3x2mm_P0.5mm
U2: TLV75518PDBVR; SOT-23-5
U3: VL53L8CXV0GC_1; VL53L8CXV0GC1; Mouser Part Number 511-VL53L8CXV0GC/1

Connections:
+1V8: C4.1, C7.1, C8.1, C9.1, C10.1, Q1.1 (G), Q2.1 (G), R1.1, R2.1, R12.1, R13.1, R14.1, TP2.1 (1_1), U1.2 (VREF1), U2.5 (OUT), U3.A3 (IOVDD), U3.B7 (CORE_1V8)
+3V3: C1.1, C3.1, C5.1, C6.1, IC1.2 (VDD), IC1.4 (SPI_CS), IC1.13 (VDDIO), J1.8, J2.1, R5.1, R6.1, R7.1, R8.1, R9.1, TP1.1 (1_1), U2.1 (IN), U2.3 (EN), U3.C4 (AVDD)
/I2C_SCL: IC1.1 (SCL/SPI_SCK), J1.5, J2.4, R7.2, U1.6 (SCL2)
/I2C_SDA: IC1.16 (SDA/SPI_SDI), J1.6, J2.3, R5.2, U1.5 (SDA2)
/LED: J1.1, J2.8, R4.1
/MAG_CAP: C2.1, IC1.10 (CAP)
/MAG_INT: IC1.15 (INT), J1.2, J2.7, R3.1
/PCA_EN: R6.2, U1.7 (VREF2), U1.8 (EN)
/TOF_INT: J1.3, J2.6, Q2.3 (D), R9.2
/TOF_INT_1V8: Q2.2 (S), R13.2, TP6.1 (1_1), U3.1 (GPIO1_1), U3.A1 (GPIO1_2)
/TOF_LPN: J1.4, J2.5, Q1.3 (D), R8.2
/TOF_LPN_1V8: Q1.2 (S), R14.2, U3.A2 (LPN)
/TOF_NCS: R11.1, U3.C2 (NCS)
/TOF_SCL: R2.2, TP5.1 (1_1), U1.3 (SCL1), U3.A5 (SCL/MCLK)
/TOF_SDA: R1.2, TP4.1 (1_1), U1.4 (SDA1), U3.A4 (SDA/MOSI)
/TOF_SPI_I2C_N: R10.1, U3.C1 (SPI_I2C_N)
/TOF_SYNC: R12.2, U3.B1 (GPIO2)
GND: C1.2, C2.2, C3.2, C4.2, C5.2, C6.2, C7.2, C8.2, C9.2, C10.2, D1.1 (K), IC1.9 (GND_1), IC1.11 (GND_2), J1.7, J2.2, R3.2, R10.2, R11.2, TP3.1 (1_1), U1.1 (GND), U2.2 (GND), U3.A6 (RSVD1), U3.A7 (RSVD2), U3.B4 (GND_1), U3.C3 (GND_2), U3.C6 (RSVD3), U3.C7 (GND_3)
unnamed: D1.2 (A), R4.2

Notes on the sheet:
Magnetometer
ToF Sensor
Board Mounting Holes
Raspberry Pi Camera Mount
Level Shifting
1.8V LDO
Connector

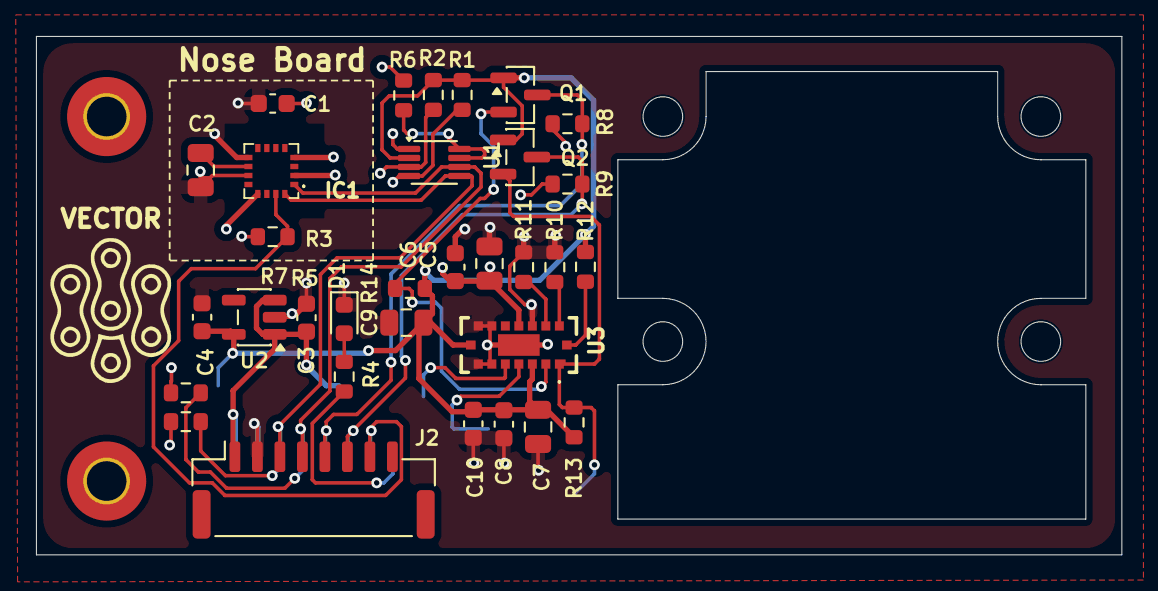
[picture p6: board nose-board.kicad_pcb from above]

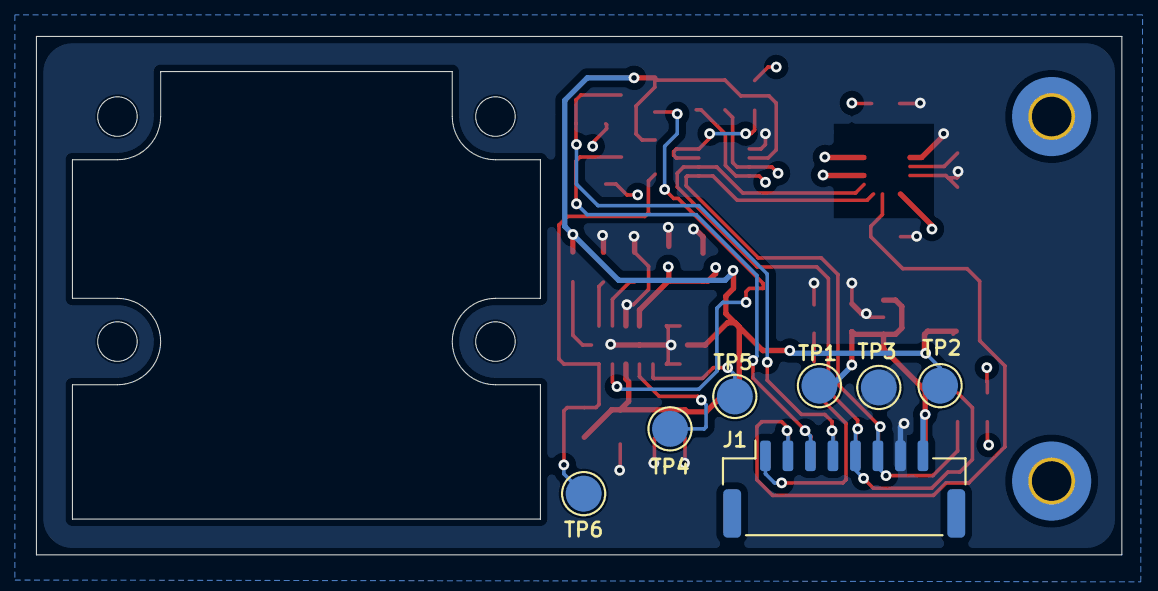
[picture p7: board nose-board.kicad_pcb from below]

Board: 4 copper layers, 60.3 x 28.8 mm, 45 parts (7 on the bottom side), 19 nets.

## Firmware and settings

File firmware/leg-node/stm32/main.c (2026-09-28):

/* Leg node on the STM32C092: peripherals, the leg_hal implementation and the 1 ms loop. */

#include <string.h>

#include "board.h"
#include "boot.h"
#include "fw_version.h"
#include "leg.h"
#include "vl53l1x.h"

#define ADC_ROUNDS 16
#define ADC_CH (3 + ADC_EXTRA_CHANNELS)
#define I2C_TIMING_400K 0x50330309u /* RM table for a 48 MHz I2C clock */
#define TOF_POLL_MS 5
#define TOF_STALE_MS 200
#define TXQ_LEN 16

static ADC_HandleTypeDef hadc;
static DMA_HandleTypeDef hdma;
static TIM_HandleTypeDef htim;
static FDCAN_HandleTypeDef hcan;
static IWDG_HandleTypeDef hiwdg;
static I2C_HandleTypeDef hi2c;
static struct vl53l1x tof;
static uint16_t tof_last_mm;
static uint32_t tof_last_t;
static volatile uint16_t adc_buf[ADC_ROUNDS * ADC_CH] __attribute__((aligned(4)));
static struct leg leg;
static uint32_t can_tx_dropped, can_bus_off;
/* the controller holds 3 frames; a self-test or calibration result comes as a burst of up to 8 */
static struct can_frame_t txq[TXQ_LEN];
static uint8_t txq_head, txq_n;

void SysTick_Handler(void) { HAL_IncTick(); }

static void gpio(void)
{
    board_gpio();
    GPIO_InitTypeDef g;

    g = (GPIO_InitTypeDef){.Pin = DBG_PIN, .Mode = GPIO_MODE_OUTPUT_PP, .Speed = GPIO_SPEED_FREQ_HIGH};
    HAL_GPIO_Init(DBG_PORT, &g);

    g = (GPIO_InitTypeDef){.Pin = POT_PINS, .Mode = GPIO_MODE_ANALOG};
    HAL_GPIO_Init(POT_PORT, &g);
#if ADC_EXTRA_CHANNELS
    g.Pin = EXTRA_PINS;
    HAL_GPIO_Init(GPIOA, &g);
#endif

    g = (GPIO_InitTypeDef){.Pin = PWM_PINS, .Mode = GPIO_MODE_AF_PP, .Speed = GPIO_SPEED_FREQ_LOW,
                           .Alternate = GPIO_AF2_TIM1};
    HAL_GPIO_Init(PWM_PORT, &g);

    g = (GPIO_InitTypeDef){.Pin = TOF_I2C_PINS, .Mode = GPIO_MODE_AF_OD, .Pull = GPIO_PULLUP,
                           .Speed = GPIO_SPEED_FREQ_HIGH, .Alternate = GPIO_AF6_I2C1};
    HAL_GPIO_Init(TOF_PORT, &g);
    HAL_GPIO_WritePin(TOF_PORT, TOF_XSHUT_PIN, GPIO_PIN_RESET); /* sensor held in reset until tof_start() */
    g = (GPIO_InitTypeDef){.Pin = TOF_XSHUT_PIN, .Mode = GPIO_MODE_OUTPUT_PP};
    HAL_GPIO_Init(TOF_PORT, &g);

#if defined(BOARD_SIDE)
    g = (GPIO_InitTypeDef){.Pin = BUCK_PG_PIN, .Mode = GPIO_MODE_INPUT};
    HAL_GPIO_Init(BUCK_PG_PORT, &g);
    g = (GPIO_InitTypeDef){.Pin = ESTOP_PIN, .Mode = GPIO_MODE_INPUT, .Pull = GPIO_PULLUP};
    HAL_GPIO_Init(ESTOP_PORT, &g);
#endif
}

static void pwm_timer(void)
{
    __HAL_RCC_TIM1_CLK_ENABLE();
    htim.Instance = TIM1;
    htim.Init.Prescaler = 47; /* 1 MHz: compare values are microseconds */
    htim.Init.Period = 19999; /* 50 Hz */
    htim.Init.CounterMode = TIM_COUNTERMODE_UP;
    htim.Init.AutoReloadPreload = TIM_AUTORELOAD_PRELOAD_ENABLE;
    if (HAL_TIM_PWM_Init(&htim) != HAL_OK)
        mcu_fail();
    TIM_OC_InitTypeDef oc = {.OCMode = TIM_OCMODE_PWM1, .Pulse = 0, .OCPolarity = TIM_OCPOLARITY_HIGH};
    const uint32_t ch[3] = {TIM_CHANNEL_1, TIM_CHANNEL_2, TIM_CHANNEL_3};
    for (int i = 0; i < 3; i++)
        if (HAL_TIM_PWM_ConfigChannel(&htim, &oc, ch[i]) != HAL_OK || HAL_TIM_PWM_Start(&htim, ch[i]) != HAL_OK)
            mcu_fail();
}

static void adc(void)
{
    __HAL_RCC_ADC_CLK_ENABLE();
    __HAL_RCC_DMA1_CLK_ENABLE();

    hdma.Instance = DMA1_Channel1;
    hdma.Init.Request = DMA_REQUEST_ADC1;
    hdma.Init.Direction = DMA_PERIPH_TO_MEMORY;
    hdma.Init.PeriphInc = DMA_PINC_DISABLE;
    hdma.Init.MemInc = DMA_MINC_ENABLE;
    hdma.Init.PeriphDataAlignment = DMA_PDATAALIGN_HALFWORD;
    hdma.Init.MemDataAlignment = DMA_MDATAALIGN_HALFWORD;
    hdma.Init.Mode = DMA_CIRCULAR;
    hdma.Init.Priority = DMA_PRIORITY_LOW;
    if (HAL_DMA_Init(&hdma) != HAL_OK)
        mcu_fail();
    __HAL_LINKDMA(&hadc, DMA_Handle, hdma);

    /* 24 MHz ADC clock, 160.5 + 12.5 cycles per sample: one pass over all channels ~50 us,
       so the 16 samples the median sees span most of a millisecond */
    hadc.Instance = ADC1;
    hadc.Init.ClockPrescaler = ADC_CLOCK_SYNC_PCLK_DIV2;
    hadc.Init.Resolution = ADC_RESOLUTION_12B;
    hadc.Init.DataAlign = ADC_DATAALIGN_RIGHT;
    hadc.Init.ScanConvMode = ADC_SCAN_SEQ_FIXED;
    hadc.Init.EOCSelection = ADC_EOC_SEQ_CONV;
    hadc.Init.ContinuousConvMode = ENABLE;
    hadc.Init.ExternalTrigConv = ADC_SOFTWARE_START;
    hadc.Init.DMAContinuousRequests = ENABLE;
    hadc.Init.Overrun = ADC_OVR_DATA_OVERWRITTEN;
    hadc.Init.SamplingTimeCommon1 = ADC_SAMPLETIME_160CYCLES_5;
    if (HAL_ADC_Init(&hadc) != HAL_OK)
        mcu_fail();

    const uint32_t pots[] = POT_CHANNELS;
    ADC_ChannelConfTypeDef ch = {.Rank = ADC_RANK_CHANNEL_NUMBER, .SamplingTime = ADC_SAMPLINGTIME_COMMON_1};
    for (int i = 0; i < 3; i++) {
        ch.Channel = pots[i];
        if (HAL_ADC_ConfigChannel(&hadc, &ch) != HAL_OK)
            mcu_fail();
    }
#if ADC_EXTRA_CHANNELS
    const uint32_t extra[] = EXTRA_CHANNELS;
    for (int i = 0; i < ADC_EXTRA_CHANNELS; i++) {
        ch.Channel = extra[i];
        if (HAL_ADC_ConfigChannel(&hadc, &ch) != HAL_OK)
            mcu_fail();
    }
#endif
    if (HAL_ADCEx_Calibration_Start(&hadc) != HAL_OK ||
        HAL_ADC_Start_DMA(&hadc, (uint32_t *)(uintptr_t)adc_buf, ADC_ROUNDS * ADC_CH) != HAL_OK)
        mcu_fail();
}

static bool tof_write(void *ctx, uint16_t reg, const uint8_t *data, int n)
{
    (void)ctx;
    return HAL_I2C_Mem_Write(&hi2c, VL53L1X_ADDR << 1, reg, I2C_MEMADD_SIZE_16BIT, (uint8_t *)data, n, 3) == HAL_OK;
}

static bool tof_read(void *ctx, uint16_t reg, uint8_t *data, int n)
{
    (void)ctx;
    return HAL_I2C_Mem_Read(&hi2c, VL53L1X_ADDR << 1, reg, I2C_MEMADD_SIZE_16BIT, data, n, 3) == HAL_OK;
}

/* XSHUT low resets the sensor, which lets go of a bus it was holding; the I2C block
   gets a fresh start with it */
static void tof_shutdown(void *ctx, bool off)
{
    (void)ctx;
    HAL_GPIO_WritePin(TOF_PORT, TOF_XSHUT_PIN, off ? GPIO_PIN_RESET : GPIO_PIN_SET);
    if (off && (HAL_I2C_DeInit(&hi2c) != HAL_OK || HAL_I2C_Init(&hi2c) != HAL_OK))
        mcu_fail();
}

static void tof_start(void)
{
    __HAL_RCC_I2C1_CLK_ENABLE();
    hi2c.Instance = I2C1;
    hi2c.Init.Timing = I2C_TIMING_400K;
    hi2c.Init.AddressingMode = I2C_ADDRESSINGMODE_7BIT;
    hi2c.Init.DualAddressMode = I2C_DUALADDRESS_DISABLE;
    hi2c.Init.GeneralCallMode = I2C_GENERALCALL_DISABLE;
    hi2c.Init.NoStretchMode = I2C_NOSTRETCH_DISABLE;
    if (HAL_I2C_Init(&hi2c) != HAL_OK)
        mcu_fail();
    tof = (struct vl53l1x){.write = tof_write, .read = tof_read, .shutdown = tof_shutdown};
    vl53l1x_begin(&tof, VL53L1X_SHORT, 20, 25);
}

/* the driver finds the sensor, also one plugged in later, and never blocks for long */
static void tof_poll(uint32_t t)
{
    uint16_t mm;
    uint8_t status;
    if (t % TOF_POLL_MS == 0 && vl53l1x_run(&tof, t, &mm, &status) == 1) {
        tof_last_mm = mm;
        tof_last_t = t;
    }
}

static void watchdog(void)
{
    hiwdg.Instance = IWDG;
    hiwdg.Init.Prescaler = IWDG_PRESCALER_32; /* ~1 kHz from LSI */
    hiwdg.Init.Reload = 100;                  /* 100 ms: a hung loop resets, the buck enable drops */
    hiwdg.Init.Window = IWDG_WINDOW_DISABLE;
    if (HAL_IWDG_Init(&hiwdg) != HAL_OK)
        mcu_fail();
}

/* ---- leg_hal ---- */

static uint32_t hal_now(void *ctx) { (void)ctx; return HAL_GetTick(); }

static void hal_pwm(void *ctx, int joint, int us)
{
    (void)ctx;
    static const uint32_t ch[3] = {TIM_CHANNEL_1, TIM_CHANNEL_2, TIM_CHANNEL_3};
    __HAL_TIM_SET_COMPARE(&htim, ch[joint], us);
}

static void hal_adc(void *ctx, int ch, uint16_t *out, int n)
{
    (void)ctx;
    int slot = ch <= ADC_POT2 ? ch : 3 + (ch - ADC_I_LEG);
    if (slot >= ADC_CH) {
        /* not wired on this board: fixed, harmless values */
        uint16_t v = ch == ADC_NTC ? 1650 : 0;
        for (int i = 0; i < n; i++)
            out[i] = v;
        return;
    }
    /* more than the buffer holds repeats it, which leaves the median where it was */
    for (int i = 0; i < n; i++)
        out[i] = (uint16_t)(adc_buf[(i % ADC_ROUNDS) * ADC_CH + slot] * 3300u / 4095u);
}

static void hal_buck(void *ctx, bool on)
{
    (void)ctx;
#if defined(BOARD_NUCLEO)
    (void)on;
#else
    HAL_GPIO_WritePin(BUCK_EN_PORT, BUCK_EN_PIN, on ? GPIO_PIN_SET : GPIO_PIN_RESET);
#endif
}

static bool hal_buck_good(void *ctx)
{
    (void)ctx;
#if defined(BOARD_NUCLEO)
    return true;
#else
    return HAL_GPIO_ReadPin(BUCK_PG_PORT, BUCK_PG_PIN) == GPIO_PIN_SET;
#endif
}

static bool hal_estop(void *ctx)
{
    (void)ctx;
#if defined(BOARD_NUCLEO)
    return false;
#else
    return HAL_GPIO_ReadPin(ESTOP_PORT, ESTOP_PIN) == GPIO_PIN_RESET;
#endif
}

static uint8_t hal_leg_id(void *ctx) { (void)ctx; return board_node_id(); }

/* 0 = no sensor or no fresh reading, 0xffff = nothing in range */
static uint16_t hal_tof(void *ctx)
{
    (void)ctx;
    return vl53l1x_ranging(&tof) && HAL_GetTick() - tof_last_t < TOF_STALE_MS ? tof_last_mm : 0;
}

static void can_flush(void)
{
    while (txq_n && mcu_can_send(&hcan, &txq[txq_head])) {
        txq_head = (txq_head + 1) % TXQ_LEN;
        txq_n--;
    }
}

static void hal_send(void *ctx, const struct can_frame_t *f)
{
    (void)ctx;
    can_flush();
    if (txq_n == 0 && mcu_can_send(&hcan, f))
        return;
    if (txq_n == TXQ_LEN) {
        can_tx_dropped++;
        return;
    }
    txq[(txq_head + txq_n++) % TXQ_LEN] = *f;
}

static bool hal_save(void *ctx, int slot, const void *data, int len)
{
    (void)ctx;
    const uint32_t addr = CONFIG_ADDR + (slot ? FLASH_PAGE_SIZE : 0);
    uint64_t words[(sizeof(struct leg_config) + 7) / 8];
    if (len > (int)sizeof(words))
        return false;
    memset(words, 0xff, sizeof(words));
    memcpy(words, data, len);

    FLASH_EraseInitTypeDef erase = {.TypeErase = FLASH_TYPEERASE_PAGES,
                                    .Page = (addr - FLASH_BASE) / FLASH_PAGE_SIZE, .NbPages = 1};
    uint32_t bad;
    bool ok = HAL_FLASH_Unlock() == HAL_OK;
    HAL_IWDG_Refresh(&hiwdg);
    ok = ok && HAL_FLASHEx_Erase(&erase, &bad) == HAL_OK;
    for (unsigned i = 0; ok && i < sizeof(words) / 8; i++)
        ok = HAL_FLASH_Program(FLASH_TYPEPROGRAM_DOUBLEWORD, addr + 8 * i, words[i]) == HAL_OK;
    HAL_FLASH_Lock();
    return ok && memcmp((const void *)addr, data, len) == 0;
}

static uint32_t hal_diag(void *ctx, uint8_t key)
{
    (void)ctx;
    switch (key) {
    case KEY_VERSION: return FW_VERSION;
    case KEY_RESET_CAUSE: return BOOT_RESET_CAUSE;
    case KEY_ID_STRAPS: return board_id_straps();
    case KEY_CAN_ERRORS: return (can_bus_off > 0xffff ? 0xffff : can_bus_off) << 16 | (can_tx_dropped > 0xffff ? 0xffff : can_tx_dropped);
    }
    return 0;
}

static const struct leg_hal hal = {
    NULL, hal_now, hal_pwm, hal_adc, hal_buck, hal_buck_good, hal_estop, hal_leg_id, hal_tof, hal_send, hal_save, hal_diag,
};

static void boot_send(void *ctx, const struct can_frame_t *f) { (void)ctx; mcu_can_send(&hcan, f); }

static void enter_bootloader(void)
{
    /* only while the servos are unpowered and nothing is moving */
    static const struct boot_io io = {.send = boot_send};
    if (leg.state != LEG_OFF && leg.state != LEG_FAULT) {
        boot_reply(&io, leg.node, BOOT_ENTER, BOOT_BUSY, 0);
        return;
    }
    hal_buck(NULL, false);
    BOOT_FLAG = BOOT_FLAG_ENTER;
    HAL_Delay(1); /* let the CAN controller finish sending */
    NVIC_SystemReset();
}

static void can_poll(void)
{
    struct can_frame_t f;
    while (mcu_can_recv(&hcan, &f)) {
        if (boot_is_enter(&f, leg.node))
            enter_bootloader();
        else
            leg_frame(&leg, &f);
    }
}

static void led(uint32_t t)
{
    /* on: active; fast blink: fault, wake or a bad leg ID; double blink: calibrating or
       self-test; off: the leg number every 3 s, short blinks left, long blinks right */
    bool on;
    switch (leg.state) {
    case LEG_ACTIVE: on = true; break;
    case LEG_FAULT:
    case LEG_WAKE: on = t % 200 < 100; break;
    case LEG_CALIBRATE:
    case LEG_TEST: on = t % 1000 < 100 || (t % 1000 >= 200 && t % 1000 < 300); break;
    default:
        if (leg.node < 1 || leg.node > 6) {
            on = t % 200 < 100;
        } else {
            uint32_t n = (leg.node - 1) % 3 + 1, slot = t % 3000 / 500, in_slot = t % 500;
            on = slot < n && in_slot < (leg.node > 3 ? 350u : 100u);
        }
    }
    HAL_GPIO_WritePin(LED_PORT, LED_PIN, on ? GPIO_PIN_SET : GPIO_PIN_RESET);
}

int main(void)
{
    HAL_Init();
    mcu_clocks();
    gpio();
    pwm_timer();
    adc();
    mcu_can(&hcan, board_node_id());
    tof_start();
    HAL_Delay(2); /* the DMA fills the ADC buffer once */

    leg_init(&leg, &hal, (const struct leg_config *)CONFIG_ADDR,
             (const struct leg_config *)(CONFIG_ADDR + FLASH_PAGE_SIZE));
    watchdog();

    uint32_t last = HAL_GetTick();
    for (;;) {
        if (mcu_can_recover(&hcan))
            can_bus_off++;
        can_flush();
        can_poll();
        uint32_t t = HAL_GetTick();
        if (t != last) {
            last = t;
            DBG_PORT->BSRR = DBG_PIN;
            tof_poll(t);
            leg_tick(&leg);
            led(t);
            HAL_IWDG_Refresh(&hiwdg);
            DBG_PORT->BRR = DBG_PIN;
        }
    }
}

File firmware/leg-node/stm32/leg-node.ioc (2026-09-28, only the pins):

Mcu.UserName=STM32C092KCTx
PA0.GPIO_Label=ADC_POT_COXA
PA0.Signal=ADC1_IN0
PA1.GPIO_Label=ADC_POT_FEMUR
PA1.Signal=ADC1_IN1
PA10.GPIO_Label=TIM_PWM_TIBIA
PA10.Signal=S_TIM1_CH3
PA13.Signal=DEBUG_SWDIO
PA14-BOOT0.Signal=DEBUG_SWCLK
PA15.GPIO_Label=LED
PA15.Signal=GPIO_Output
PA2.GPIO_Label=ADC_POT_TIBIA
PA2.Signal=ADC1_IN2
PA3.GPIO_Label=ADC_I_LEG
PA3.Signal=ADC1_IN3
PA4.GPIO_Label=NTC_SENSE
PA4.Signal=ADC1_IN4
PA5.GPIO_Label=ADC_VBAT
PA5.Signal=ADC1_IN5
PA6.GPIO_Label=ADC_6V0
PA6.Signal=ADC1_IN6
PA7.GPIO_Label=DBG
PA7.Signal=GPIO_Output
PA8.GPIO_Label=TIM_PWM_COXA
PA8.Signal=S_TIM1_CH1
PA9.GPIO_Label=TIM_PWM_FEMUR
PA9.Signal=S_TIM1_CH2
PB0.GPIO_Label=BUCK_EN
PB0.Signal=GPIO_Output
PB1.GPIO_Label=BUCK_PG
PB1.Signal=GPIO_Input
PB2.GPIO_Label=GPIO_ESTOP
PB2.Signal=GPIO_Input
PB3.GPIO_Label=LEG_ID_B0
PB3.Signal=GPIO_Input
PB4.GPIO_Label=TOF_INT
PB4.Signal=GPIO_Input
PB5.GPIO_Label=TOF_XSHUT
PB5.Signal=GPIO_Output
PB6.GPIO_Label=TOF_SCL
PB6.Signal=I2C1_SCL
PB7.GPIO_Label=TOF_SDA
PB7.Signal=I2C1_SDA
PB8.GPIO_Label=LEG_ID_B1
PB8.Signal=GPIO_Input
PB9.GPIO_Label=SIDE_BIT
PB9.Signal=GPIO_Input
PC14-OSCX_IN(PC14).Signal=RCC_OSCX_IN
PC15-OSCX_OUT(PC15).Signal=RCC_OSCX_OUT

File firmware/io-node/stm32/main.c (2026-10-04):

/* IO MCU on the STM32C092: four UARTs on interrupts and ring buffers, SPI1 to the RFM95W,
   ADC, the two PWM timers, and the io_hal for the logic in src/. */

#include <string.h>

#include "board.h"
#include "fw_version.h"
#include "io.h"

#define PCLK_HZ 48000000u
#define BOOT_FLAG_ROM 0xB0075707u /* set before a reset: start ST's ROM bootloader */
#define SYSMEM_ADDR 0x1FFF0000u

/* ---- UARTs ---- */

struct uart {
    USART_TypeDef *u;
    uint8_t *rx, *tx;
    uint16_t rx_size, tx_size; /* powers of two */
    volatile uint16_t rx_head, rx_tail, tx_head, tx_tail;
    volatile uint32_t errors;
};

static uint8_t host_rx[512], host_tx[4096], elrs_rx[256], elrs_tx[128], lidar_rx[512], gnss_rx[512];
static struct uart uarts[PORTS] = {
    [PORT_HOST] = {USART1, host_rx, host_tx, sizeof(host_rx), sizeof(host_tx)},
    [PORT_ELRS] = {USART2, elrs_rx, elrs_tx, sizeof(elrs_rx), sizeof(elrs_tx)},
    [PORT_LIDAR] = {USART4, lidar_rx, NULL, sizeof(lidar_rx), 0},
    [PORT_GNSS] = {USART3, gnss_rx, NULL, sizeof(gnss_rx), 0},
};

static void uart_init(struct uart *p, uint32_t baud, bool tx)
{
    USART_TypeDef *u = p->u;
    u->CR1 = 0;
    u->BRR = (PCLK_HZ + baud / 2) / baud;
    u->CR3 = 0; /* overruns are flagged and counted */
    u->CR1 = USART_CR1_RE | (tx ? USART_CR1_TE : 0) | USART_CR1_RXNEIE_RXFNEIE | USART_CR1_UE;
}

static void uart_irq(struct uart *p)
{
    USART_TypeDef *u = p->u;
    const uint32_t isr = u->ISR;
    if (isr & (USART_ISR_ORE | USART_ISR_FE | USART_ISR_NE)) {
        u->ICR = USART_ICR_ORECF | USART_ICR_FECF | USART_ICR_NECF;
        p->errors++;
    }
    if (isr & USART_ISR_RXNE_RXFNE) {
        const uint8_t b = (uint8_t)u->RDR;
        const uint16_t next = (p->rx_head + 1) & (p->rx_size - 1);
        if (next != p->rx_tail) {
            p->rx[p->rx_head] = b;
            p->rx_head = next;
        } else {
            p->errors++;
        }
    }
    if ((u->CR1 & USART_CR1_TXEIE_TXFNFIE) && (isr & USART_ISR_TXE_TXFNF)) {
        if (p->tx_tail != p->tx_head) {
            u->TDR = p->tx[p->tx_tail];
            p->tx_tail = (p->tx_tail + 1) & (p->tx_size - 1);
        } else {
            u->CR1 &= ~USART_CR1_TXEIE_TXFNFIE;
        }
    }
}

void USART1_IRQHandler(void) { uart_irq(&uarts[PORT_HOST]); }
void USART2_IRQHandler(void) { uart_irq(&uarts[PORT_ELRS]); }
void USART3_4_IRQHandler(void)
{
    uart_irq(&uarts[PORT_GNSS]);
    uart_irq(&uarts[PORT_LIDAR]);
}

static bool uart_write(struct uart *p, const uint8_t *d, int n)
{
    if (!p->tx_size)
        return false;
    const uint16_t used = (p->tx_head - p->tx_tail) & (p->tx_size - 1);
    if (n > p->tx_size - 1 - used)
        return false;
    uint16_t h = p->tx_head;
    for (int i = 0; i < n; i++) {
        p->tx[h] = d[i];
        h = (h + 1) & (p->tx_size - 1);
    }
    p->tx_head = h;
    p->u->CR1 |= USART_CR1_TXEIE_TXFNFIE; /* a race with the ISR clearing it only costs one empty interrupt */
    return true;
}

static int uart_read(struct uart *p, uint8_t *d, int max)
{
    int n = 0;
    while (n < max && p->rx_tail != p->rx_head) {
        d[n++] = p->rx[p->rx_tail];
        p->rx_tail = (p->rx_tail + 1) & (p->rx_size - 1);
    }
    return n;
}

static void uarts_init(void)
{
    __HAL_RCC_USART1_CLK_ENABLE();
    __HAL_RCC_USART2_CLK_ENABLE();
    __HAL_RCC_USART3_CLK_ENABLE();
    __HAL_RCC_USART4_CLK_ENABLE();
    uart_init(&uarts[PORT_HOST], 1000000, true);
    uart_init(&uarts[PORT_ELRS], 420000, true);
    uart_init(&uarts[PORT_LIDAR], 115200, false); /* LDS01RR, XV-11 protocol */
    uart_init(&uarts[PORT_GNSS], 9600, true); /* the MAX-M10S default */
    HAL_NVIC_SetPriority(USART1_IRQn, 1, 0);
    HAL_NVIC_SetPriority(USART2_IRQn, 0, 0); /* 420 kbaud, the shortest byte time */
    HAL_NVIC_SetPriority(USART3_4_IRQn, 1, 0);
    HAL_NVIC_EnableIRQ(USART1_IRQn);
    HAL_NVIC_EnableIRQ(USART2_IRQn);
    HAL_NVIC_EnableIRQ(USART3_4_IRQn);
}

/* ---- SPI1 to the RFM95W, polled, 6 MHz ---- */

static uint8_t spi_byte(uint8_t b)
{
    while (!(SPI1->SR & SPI_SR_TXE)) {
    }
    *(volatile uint8_t *)&SPI1->DR = b;
    while (!(SPI1->SR & SPI_SR_RXNE)) {
    }
    return *(volatile uint8_t *)&SPI1->DR;
}

static void spi_init(void)
{
    __HAL_RCC_SPI1_CLK_ENABLE();
    SPI1->CR1 = 0;
    SPI1->CR2 = SPI_CR2_FRXTH | (7u << SPI_CR2_DS_Pos); /* 8-bit, RXNE at one byte */
    SPI1->CR1 = SPI_CR1_MSTR | SPI_CR1_SSM | SPI_CR1_SSI | (2u << SPI_CR1_BR_Pos) | SPI_CR1_SPE; /* /8 */
}

static void radio_xfer(uint8_t addr, uint8_t *data, const uint8_t *out, int n)
{
    HAL_GPIO_WritePin(LORA_NSS_PORT, LORA_NSS_PIN, GPIO_PIN_RESET);
    spi_byte(addr);
    for (int i = 0; i < n; i++) {
        const uint8_t r = spi_byte(out ? out[i] : 0);
        if (data)
            data[i] = r;
    }
    while (SPI1->SR & SPI_SR_BSY) {
    }
    HAL_GPIO_WritePin(LORA_NSS_PORT, LORA_NSS_PIN, GPIO_PIN_SET);
}

static void radio_read(void *ctx, uint8_t reg, uint8_t *data, int n) { (void)ctx; radio_xfer(reg & 0x7F, data, NULL, n); }
static void radio_write(void *ctx, uint8_t reg, const uint8_t *data, int n) { (void)ctx; radio_xfer(reg | 0x80, NULL, data, n); }
static const struct sx1276_io radio_io = {.read = radio_read, .write = radio_write};

/* ---- ADC, VDDA from VREFINT ---- */

static void adc_init(void)
{
    __HAL_RCC_ADC_CLK_ENABLE();
    ADC1->CFGR2 = 2u << ADC_CFGR2_CKMODE_Pos; /* PCLK / 4 = 12 MHz */
    ADC1->SMPR = 7u << ADC_SMPR_SMP1_Pos;      /* 160.5 cycles: the 100k divider needs time */
    ADC1_COMMON->CCR |= ADC_CCR_VREFEN;
    ADC1->CR = ADC_CR_ADVREGEN;
    HAL_Delay(1);
    ADC1->CR |= ADC_CR_ADCAL;
    while (ADC1->CR & ADC_CR_ADCAL) {
    }
    ADC1->ISR = ADC_ISR_ADRDY;
    ADC1->CR |= ADC_CR_ADEN;
    while (!(ADC1->ISR & ADC_ISR_ADRDY)) {
    }
}

static uint32_t adc_raw(uint32_t ch)
{
    ADC1->CHSELR = 1u << ch;
    while (!(ADC1->ISR & ADC_ISR_CCRDY)) {
    }
    ADC1->ISR = ADC_ISR_CCRDY;
    uint32_t sum = 0;
    for (int i = 0; i < 8; i++) {
        ADC1->CR |= ADC_CR_ADSTART;
        while (!(ADC1->ISR & ADC_ISR_EOC)) {
        }
        sum += ADC1->DR;
    }
    return sum / 8;
}

/* ---- timers: TIM3_CH4 lidar motor PWM at 30 kHz, TIM14_CH1 buzzer from a 1 MHz count ---- */

#define LIDAR_PWM_ARR 1599u

static void timers_init(void)
{
    __HAL_RCC_TIM3_CLK_ENABLE();
    __HAL_RCC_TIM14_CLK_ENABLE();
    TIM3->PSC = 0;
    TIM3->ARR = LIDAR_PWM_ARR;
    TIM3->CCR4 = 0;
    TIM3->CCMR2 = (6u << TIM_CCMR2_OC4M_Pos) | TIM_CCMR2_OC4PE; /* PWM mode 1 */
    TIM3->CCER = TIM_CCER_CC4E;
    TIM3->EGR = TIM_EGR_UG;
    TIM3->CR1 = TIM_CR1_ARPE | TIM_CR1_CEN;

    TIM14->PSC = PCLK_HZ / 1000000u - 1;
    TIM14->ARR = 999;
    TIM14->CCR1 = 0;
    TIM14->CCMR1 = (6u << TIM_CCMR1_OC1M_Pos) | TIM_CCMR1_OC1PE;
    TIM14->CCER = TIM_CCER_CC1E;
    TIM14->EGR = TIM_EGR_UG;
    TIM14->CR1 = TIM_CR1_ARPE | TIM_CR1_CEN;
}

/* ---- io_hal ---- */

static IWDG_HandleTypeDef hiwdg;
static uint32_t vdda_mv = 3300;
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

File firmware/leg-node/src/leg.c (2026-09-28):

#include "leg.h"

#include <math.h>
#include <string.h>

#include "board.h"

#define SAMPLES 16
#define RESUME_MARGIN_US 30.0f
#define WAKE_SETTLE_MS 150
#define WAKE_BUCK_MS 60
#define TEST_DEG 5.0f
#define TEST_TOL_DEG 2.0f
#define TEST_TIMEOUT_MS 400
#define WAKE_TRIES 3
#define SYNC_TIMEOUT_MS 100
#define CROUCH_MS 2000
#define CROUCH_SPEED 30.0f /* deg/s */
#define MAX_SPEED 400.0f
#define IDLE_TX_MS 50
#define CAL_START_MS 800
#define CAL_SETTLE_MS 400
#define CAL_MAX_ERR_MV 60.0f
#define CAL_MIN_SPAN_MV 200.0f
#define OVERLOAD_MA 5000   /* three MG996Rs stalled draw ~7.5 A */
#define OVERLOAD_MS 500
#define HOT_C 85           /* NTC by the buck inductor */
#define COOL_C 70
#define PG_LOSS_MS 20
#define I_ZERO_AFTER_MS 100 /* after the buck turns off, before the amp output counts as zero */
#define TEST_OFF_MS 150
#define TEST_ON_MS 200

static const float crouch_deg[JOINTS] = {0.0f, 40.0f, -110.0f};

static uint32_t now(struct leg *l) { return l->hal->now_ms(l->hal->ctx); }

static void pwm(struct leg *l, int j, float us)
{
    if (us > 0) {
        if (us < 500) us = 500;
        if (us > 2500) us = 2500;
    }
    l->out_us[j] = us;
    l->hal->pwm_us(l->hal->ctx, j, (int)lroundf(us));
}

static void power(struct leg *l, bool on)
{
    if (on && !l->powered)
        l->power_t = now(l);
    if (!on && l->powered)
        l->off_t = now(l);
    l->powered = on;
    l->hal->buck(l->hal->ctx, on);
}

static void all_off(struct leg *l)
{
    for (int j = 0; j < JOINTS; j++)
        pwm(l, j, 0);
    power(l, false);
}

static void enter(struct leg *l, enum leg_state s)
{
    l->state = s;
    l->entered = now(l);
    if (s == LEG_OFF || s == LEG_FAULT)
        all_off(l);
    if (s == LEG_WAKE) {
        memset(&l->wake, 0, sizeof(l->wake));
        l->wake.joint = -1;
        power(l, true);
    }
}

static void reply(struct leg *l, uint8_t joint, uint8_t key, int32_t value, uint8_t seq, uint8_t status)
{
    struct can_frame_t f;
    struct leg_cfg_msg m = {joint, key, value, seq, status};
    can_pack_leg_cfg(&f, CAN_LEG_REPLY, l->node, &m);
    l->hal->send(l->hal->ctx, &f);
}

static float sample(struct leg *l, int ch, int n)
{
    uint16_t buf[64];
    l->hal->adc_mv(l->hal->ctx, ch, buf, n);
    return median_u16(buf, n);
}

static void read_inputs(struct leg *l)
{
    /* the pots are dead while the servos are unpowered: keep the last good angle */
    bool pots_live = l->powered && now(l) - l->power_t >= WAKE_BUCK_MS;
    for (int j = 0; j < JOINTS; j++) {
        l->mv[j] = sample(l, ADC_POT0 + j, SAMPLES);
        const struct joint_cfg *c = &l->cfg.joint[j];
        if (pots_live)
            l->pos_deg[j] = joint_us_to_deg(c, joint_mv_to_us(c, l->mv[j]));
    }
    /* the amp's output offset is whatever it reads with the buck off, tracked all the time */
    float i_mv = sample(l, ADC_I_LEG, 5);
    if (!l->powered && now(l) - l->off_t >= I_ZERO_AFTER_MS)
        l->i_zero_mv += (i_mv - l->i_zero_mv) * 0.05f;
    l->current_ma = (uint16_t)(fmaxf(0.0f, i_mv - l->i_zero_mv) * 1000.0f / (INA_GAIN * SHUNT_MOHM));
    l->vbat_mv = (uint16_t)(sample(l, ADC_VBAT, 5) * VBAT_RATIO * l->cfg.vbat_gain);
    l->rail_mv = (uint16_t)(sample(l, ADC_6V0, 5) * V6_RATIO * l->cfg.rail_gain);

    float v = sample(l, ADC_NTC, 5);
    if (v > 1.0f && v < VDDA_MV - 1.0f) {
        float r = NTC_PULLUP * v / (VDDA_MV - v);
        float c = 1.0f / (1.0f / 298.15f + logf(r / NTC_R25) / NTC_BETA) - 273.15f;
        l->temp_c = (int8_t)lroundf(fmaxf(-40.0f, fminf(125.0f, c))); /* a shorted NTC reads hot */
    }
}

static void send_state(struct leg *l, bool status)
{
    struct can_frame_t f;
    struct leg_state_msg s = {{l->pos_deg[0], l->pos_deg[1], l->pos_deg[2]}, l->current_ma};
    can_pack_leg_state(&f, l->node, &s);
    l->hal->send(l->hal->ctx, &f);
    if (!status)
        return;
    struct leg_status_msg st = {
        .tof_mm = l->hal->tof_mm ? l->hal->tof_mm(l->hal->ctx) : 0,
        .vbat_mv = l->vbat_mv, .rail_mv = l->rail_mv, .temp_c = l->temp_c,
        .faults = l->faults, .state = l->state,
    };
    can_pack_leg_status(&f, l->node, &st);
    l->hal->send(l->hal->ctx, &f);
}

void leg_init(struct leg *l, const struct leg_hal *hal, const struct leg_config *slot0, const struct leg_config *slot1)
{
    memset(l, 0, sizeof(*l));
    l->hal = hal;
    const struct leg_config *stored = config_newest(slot0, slot1);
    if (stored)
        l->cfg = *stored;
    else
        config_defaults(&l->cfg);
    l->node = hal->leg_id(hal->ctx);
    if (l->node < 1 || l->node > 6)
        l->faults |= FAULT_CONFIG;
    if (!config_calibrated(&l->cfg))
        l->faults |= FAULT_UNCALIBRATED;
    enter(l, LEG_OFF);
}

/* ---- wake: start each joint where it is, then prove it follows ---- */
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

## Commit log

2026-09-24 Added ROS2 testing env
    [controllers.yaml, flat.sdf, rough.sdf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]
2026-09-25 Added initial sideboard components
    [leg_cell.kicad_sch, side-board.kicad_pcb, side-board.kicad_sch]
2026-09-25 Added leg configuration bits
    [leg_cell.kicad_sch, side-board.kicad_sch]
2026-09-26 Gazebo tests & servo tests
    [side-board.kicad_sch]
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2026-09-27 Added initial leg firmware concept
    [controllers.yaml, vector.urdf.xacro]
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2026-09-28 Added TPS62933 design in schematic
    [side-board.kicad_sch]
2026-09-28 Updated TPS62933 circuit
    [side-board.kicad_sch]
2026-09-28 Added more leg firmware features
    [leg_cell.kicad_sch, side-board.kicad_sch]
2026-09-28 Updated schematic circuit for side board
    [leg_cell.kicad_sch]
2026-09-28 Updated folder structure & project design
    [controllers.yaml, vector.urdf.xacro]
2026-09-29 Updated schematic for leg
    [leg_cell.kicad_sch, side-board.kicad_sch]
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2026-09-29 Added GNSS, ToF sensors + obstacle mapping
    [flat.sdf, rough.sdf, slope.sdf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]
2026-09-30 Updated side board schematic
    [leg_cell.kicad_sch, side-board.kicad_sch]
2026-09-30 Added blank projects for other boards
    [carrier-cm5.kicad_pcb, carrier-cm5.kicad_sch, nose-board.kicad_pcb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]
2026-09-30 Segregated specific libs into shared libs
    [bms.kicad_sch, charger.kicad_sch, control.kicad_sch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]
2026-09-30 Added ELRS & Gazebo waypoint tests
    [vector.urdf.xacro]
2026-10-02 Added more ICs for power board
    [bms.kicad_sch, carrier-cm5.kicad_sch, charger.kicad_sch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]
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2026-10-03 draw power board bms, charger and mcu circuits
    [bms.kicad_sch, charger.kicad_sch, power-board.kicad_sch]
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2026-10-03 Reset annotations for power board
    [bms.kicad_sch, charger.kicad_sch, power-board.kicad_sch]
2026-10-04 add side board e-stop diode, cell fuse and connectors
    [leg_cell.kicad_sch, side-board.kicad_sch]
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2026-10-04 power board: test points
    [bms.kicad_sch, charger.kicad_sch, power-board.kicad_sch]
2026-10-04 side board: 1206 cell fuse, test points
    [leg_cell.kicad_sch, side-board.kicad_sch]
2026-10-04 nose board: tof, magnetometer, level shifting, test points
    [nose-board.kicad_sch]
2026-10-04 cm5 carrier: base on the cm5 io board, usb3, m.2, two csi, fan, test points
    [carrier-cm5.kicad_sch, cm5_highspeed.kicad_sch, cm5_io.kicad_sch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]
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2026-10-04 cm5 carrier: console header, lidar connector, gpio allocation
    [cm5_io.kicad_sch]
2026-10-04 cm5 carrier: lr1262 symbol and footprint, spec for lora and supply bridges
2026-10-04 cm5 carrier: io mcu sheet (elrs, lidar, lora, adc, buzzer) and gnss sheet
    [carrier-cm5.kicad_sch, cm5_io.kicad_sch, gnss.kicad_sch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]
2026-10-04 cm5 carrier: lora on an rfm95w
    [io_mcu.kicad_sch]
2026-10-04 cm5 carrier: a7670e lte sheet
    [carrier-cm5.kicad_sch, cm5_io.kicad_sch, io_mcu.kicad_sch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]
2026-10-04 cm5 carrier: can, imu, j-nose, swd recovery, j-sysctl gpios
    [carrier-cm5.kicad_sch, cm5_io.kicad_sch, periph.kicad_sch]
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2026-10-04 docs: io mcu, imu, lora beacon
    [vector.urdf.xacro]
2026-10-04 Updated schematic on CM5 carrier
    [carrier-cm5.kicad_sch, cm5_highspeed.kicad_sch, cm5_io.kicad_sch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]
2026-10-04 operator page: carrier and sensor panel, gnss pill, beep and lte switch
2026-10-04 operator page demo: simulated io mcu and imu behind the real bridge
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2026-10-04 Full placement of nose board PCB
    [nose-board.kicad_pcb, nose-board.kicad_sch]
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2026-10-04 side board: amrm inductors, 1206 buck input cap, xh can connector, rt no-connect
    [leg_cell.kicad_sch, side-board.kicad_sch]
2026-10-04 power board: amrm inductor, sot-223 for q204, 2.2k i2c pull-ups, 50 v charger caps, xh connectors
    [bms.kicad_sch, charger.kicad_sch, power-board.kicad_sch]
2026-10-04 carrier: xh can and sysctl connectors, io mcu wiring tidy
    [io_mcu.kicad_sch, periph.kicad_sch, power.kicad_sch]
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2026-10-04 Updated PCB of side-board
    [leg_cell.kicad_sch, side-board.kicad_pcb, side-board.kicad_sch]
2026-10-04 Updated PCB placement side-board
    [leg_cell.kicad_sch, side-board.kicad_pcb]
2026-10-05 Updated sideboard PCB
    [leg_cell.kicad_sch, power-board.kicad_sch, side-board.kicad_pcb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]
2026-10-05 Updated PCB placement sideboard
    [leg_cell.kicad_sch, side-board.kicad_pcb, side-board.kicad_sch]
2026-10-05 Compacted side board pcb
    [leg_cell.kicad_sch, side-board.kicad_pcb, side-board.kicad_sch]
2026-10-05 add lidar motor fet and xh connectors on carrier
    [io_mcu.kicad_sch]
2026-10-05 fix stale refs in io and power node pin maps
    [board_pins.h]
2026-10-05 Compacted sideboard
    [side-board.kicad_pcb]
2026-10-06 Compacted sideboard further
    [leg_cell.kicad_sch, side-board.kicad_pcb, side-board.kicad_sch]
2026-10-07 Added URDF
    [624ZBearingv1_1.stl, 624ZBearingv1_1_0.stl, 624ZBearingv1_1_1.stl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]
2026-10-07 Added fix to URDF
    [vector_cad_raw.urdf.xacro]
2026-10-07 send leg enable and estop together so a quick wake can't drop the release
2026-10-07 use the CAD leg geometry and a stance checked at 3 kg
2026-10-07 move the leg tof to the tibia, placed from the CAD
    [vector.urdf.xacro]
2026-10-07 fix stale swd and footprint notes
2026-10-07 sentinel: step the feet out before sitting so the belly reaches the ground
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2026-10-07 Added more features
    1. Gazebo sensors
    2. black box
    3. battery time
    4. return home
    5. calibration wizard
    [flat.sdf, rough.sdf, slope.sdf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]
2026-10-08 Added a secondary BOM
    [BOM_LCSC.csv]
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2026-11-02 sim_legs: --skip to share the bus with real legs
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
